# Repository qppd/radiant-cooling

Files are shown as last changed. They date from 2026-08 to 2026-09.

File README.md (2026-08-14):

# Radiant Cooling System

<p align="center">
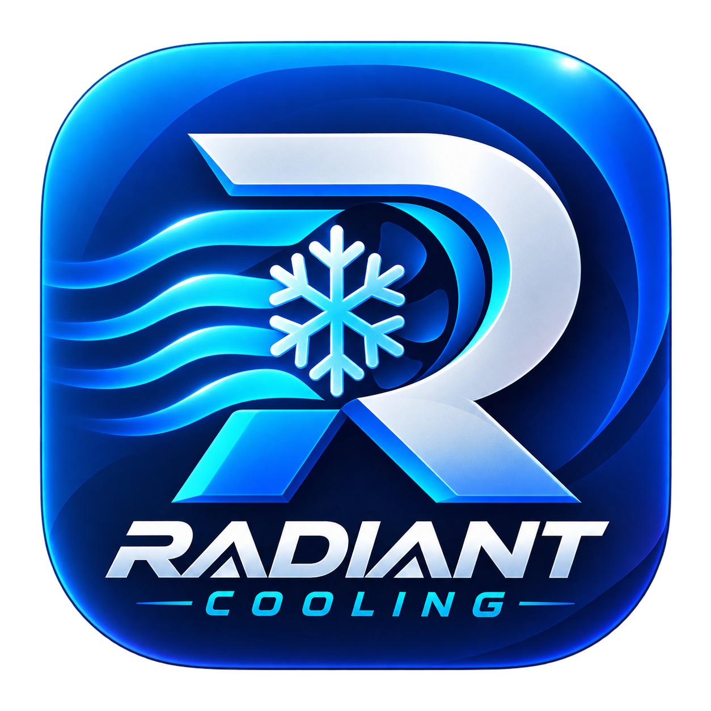
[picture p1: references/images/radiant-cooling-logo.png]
Radiant Cooling logo
  
</p>








> Intelligent radiant cooling for the home — three ESP32 boards that talk to
> each other over **ESP-NOW**, sync to **Firebase Realtime Database**, and are
> monitored from an **Android (Flutter)** app.

---

## Table of Contents

- [About](#about)
- [Features](#features)
- [System Architecture](#system-architecture)
- [Hardware](#hardware)
- [Repository Structure](#repository-structure)
- [Getting Started](#getting-started)
  - [Firmware](#firmware)
  - [Companion App](#companion-app)
- [Firebase Setup](#firebase-setup)
- [Documentation](#documentation)
- [Tech Stack](#tech-stack)
- [Roadmap](#roadmap)
- [License](#license)
- [Author](#author)

---

## About

A complete control and monitoring system for a **radiant cooling**
installation. Three ESP32 boards form a wireless mesh:

- **RadiantCoolingMonitor** (gateway) reads **6× DS18B20** water/pipe
  temperatures, collects data from the other boards, fetches outdoor
  weather (API key managed by the app), and pushes everything to Firebase —
  while also computing the chiller pump control (weather-driven +
  condensation protection).
- **WaterChillerController** switches **2 water pumps (SSR)** on command from
  the gateway.
- **DehumidifierController** holds indoor humidity at **55% RH** with its
  DHT22.

No MQTT broker, no cloud middleware — the boards use **ESP-NOW** directly,
and the gateway is the only device with Wi-Fi.

## Features

- **ESP-NOW mesh** — peer-to-peer, no router or broker required between boards
- **Two-way Firebase** — realtime *streaming* of config changes from the app,
  plus telemetry/state writes (Mobizt `FirebaseClient`, async, non-blocking)
- **Weather-aware pump control** — combines WeatherAPI.com dew point,
  indoor humidity, water/pipe temperatures and indoor air (DHT22);
  anti-condensation protection on the coldest pipe
- **Dehumidifier** — holds indoor RH at 55% with hysteresis
- **WiFiManager provisioning** — captive portal on first boot; hold the
  reset button 3 s to re-provision
- **Flutter Android app** — login/signup, live dashboard and settings
- **Modular firmware** — every component and library encapsulated in its own
  class (sensor, SSR, ESP-NOW, JSON, Firebase, Weather, Climate)

## System Architecture

```
┌────────────────┐   ESP-NOW   ┌──────────────────────────┐
│WaterChiller    │◄───────────►│RadiantCoolingMonitor     │
│Controller      │             │(gateway: WiFiManager +   │
└────────────────┘             │ Firebase stream +        │
┌────────────────┐   ESP-NOW   │ WeatherAPI + ESP-NOW)    │
│Dehumidifier    │◄───────────►│                          │
│Controller      │             └────────────┬─────────────┘
└────────────────┘                          │ HTTPS
                                            ▼
                             ┌────────────────────────────┐
                             │ Firebase Realtime Database  │
                             └────────────┬───────────────┘
                                          │ Firebase SDK
                                          ▼
                             ┌────────────────────────────┐
                             │ RadiantCooling App          │
                             │ (Flutter, Android)          │
                             └────────────────────────────┘
```

Full diagrams: [`docs/diagrams/`](docs/diagrams/) · [`docs/schematic/pin-map.md`](docs/schematic/pin-map.md)

## Hardware

| Board | Sensors | Actuators (SSR) | Role |
| --- | --- | --- | --- |
| `RadiantCoolingMonitor` | 6× DS18B20 (1-Wire, GPIO 18) | — | Gateway  |
| `WaterChillerController` | 1× DS18B20 (GPIO 22) | 2× SSR → pumps (19, 21) | Peer |
| `DehumidifierController` | 1× DHT22 (GPIO 32) | 1× SSR → dehumidifier (23)| Peer |

All pins are boot/Wi-Fi-safe for the 38-pin ESP32 variant — see the
[pin map](docs/schematic/pin-map.md).

Each board is powered by its **own** AC-DC supply (**220 V AC → 5 V DC,
3 A**, feeding the `5V`/`VIN` pin) — no shared rail between boards, see
[`references/power-supply.md`](references/power-supply.md).

## Repository Structure

```
radiant-cooling/
├── docs/
│   ├── api.md                 # ESP-NOW + Firebase protocol
│   ├── tech-stacks.md         # technology choices
│   ├── diagrams/              # architecture, block & flow diagrams
│   └── schematic/             # pin map & electrical references
├── references/                # reference material (datasheets, notes)
└── src/
    ├── app/
    │   └── RadiantCooling/    # Flutter companion app (Android)
    └── esp/
        ├── RadiantCoolingMonitor/     # gateway firmware
        ├── WaterChillerController/    # pump controller firmware
        ├── DehumidifierController/    # dehumidifier firmware
        └── README.md                  # firmware module documentation
```

## Getting Started

### Prerequisites

- [Arduino IDE 2.x](https://www.arduino.cc/en/software) with the
  **esp32 by Espressif** board package
- Arduino libraries: `DallasTemperature`, `OneWire`, `DHT sensor library`,
  `ArduinoJson`, `FirebaseClient` (Mobizt), `WiFiManager` (tzapu)
- [Flutter SDK](https://flutter.dev) (for the app)
- A [Firebase](https://firebase.google.com) project with Realtime Database
- A free [WeatherAPI.com](https://www.weatherapi.com) API key (managed from
  the Flutter app and delivered to the gateway at runtime — never compiled
  into the firmware)

### Firmware

1. Open each sketch folder in `src/esp/` with Arduino IDE, select the correct
   ESP32 board + COM port, and upload.
2. Fill in the config headers: on the gateway copy
   `FirebaseConfig.cpp.example` → `FirebaseConfig.cpp` (git-ignored), and
   set the peer/gateway MAC addresses, the `SYSTEM_ID`, and the
   `WEATHER_LOCATION` in `Config.h` for each board. The WeatherAPI key is
   managed from the Flutter app.
3. On first boot the gateway opens a **WiFiManager portal** (AP
   `RadiantCooling-AP`) — connect to it from your phone and enter your
   network credentials.
4. Fix the router to a fixed Wi-Fi channel (1, 6, or 11) so ESP-NOW works.

Details: [`src/esp/README.md`](src/esp/README.md)

### Companion App

```bash
cd src/app/RadiantCooling
flutter pub get
flutter run
```

Setup before first run:

1. Use the same Firebase project as the gateway; add the Android app
   (package `com.radiantcooling.radiant_cooling`), download
   `google-services.json` into `android/app/`, and wire the
   `google-services` Gradle plugin — see
   [`references/flutter-android-firebase.md`](references/flutter-android-firebase.md).
   Enable **Email/Password** in *Auth → Sign-in method* (the app's login
   and signup screens use it).
2. Copy `lib/config/app_config.example.dart` → `lib/config/app_config.dart`
   and fill in the **WeatherAPI.com key** (git-ignored). The app delivers
   the key to the gateway via `radiant/config/weather_key`; the **gateway
   fetches the weather itself**.
3. On first launch, **link** the app to your system by entering the
   `SYSTEM_ID` from the gateway's `Config.h` (the gateway publishes it in
   `radiant/devices/<SYSTEM_ID>`).

The app provides:

- **Login / Sign up** (email/password via Firebase Auth)
- **Device linking on first login** — new accounts (and any signed-in user
  with no linked system) are routed to a dedicated linking page where the
  `SYSTEM_ID` from the gateway is entered and validated against the device
  registry before the dashboard is shown
- **Dashboard** — live telemetry streamed from Firebase: gateway online
  status, outdoor weather (fetched by the ESP32), all pipe sensors
  (supply/return/ΔT/coldest pipe/tank + every DS18B20), pump + dehumidifier
  state, a live dew-point computation (Magnus formula from the streamed
  outdoor/indoor temp + humidity), and the gateway's condensation-safety
  values
- **Settings** — edit control parameters (comfort setpoint, dew-point
  margin, weather-cool threshold) and the dehumidifier target, link/change
  the system, manage the WeatherAPI key, and sign out

## Firebase Setup

1. Create a Firebase project and enable **Realtime Database**.
2. Enable **Email/Password** authentication in *Auth → Sign-in method*.
   Create a dedicated **gateway** account (e.g.
   `gateway@radiant-cooling.local`) and register a personal account for
   the app (the app has login and signup screens).
3. Copy `FirebaseConfig.cpp.example` → `FirebaseConfig.cpp` in the gateway
   folder and paste the database URL, **Web API key**, and (if using
   email/password auth) credentials — the file is git-ignored so secrets
   stay local.
4. Apply the security rules in
   [`docs/firebase-security-rules.json`](docs/firebase-security-rules.json)
   (paste into *Realtime Database → Rules* or deploy with
   `firebase deploy --only database`). The gateway must use a dedicated
   **email/password** account (replace the placeholder email in the rules) —
   see [`docs/api.md`](docs/api.md#8-firebase-security-rules--auth).

## Documentation

| Document | Contents |
| --- | --- |
| [`docs/api.md`](docs/api.md) | ESP-NOW protocol + Firebase data schema |
| [`docs/tech-stacks.md`](docs/tech-stacks.md) | Technology decisions |
| [`docs/diagrams/system-architecture.md`](docs/diagrams/system-architecture.md) | System layers |
| [`docs/diagrams/block-diagram.md`](docs/diagrams/block-diagram.md) | Hardware blocks |
| [`docs/diagrams/flow-chart.md`](docs/diagrams/flow-chart.md) | Control logic |
| [`docs/schematic/pin-map.md`](docs/schematic/pin-map.md) | Safe pin assignments |
| [`src/esp/README.md`](src/esp/README.md) | Firmware module layout |
| [`references/`](references/) | Per-topic references (ESP-NOW, Firebase, sensors, pins…) |

## Tech Stack

| Layer | Technology |
| --- | --- |
| Firmware | ESP32 (WROOM-32), C/C++, Arduino IDE |
| Mesh | ESP-NOW (built into the ESP32 core) |
| Cloud | Firebase Realtime Database + FirebaseClient |
| Weather | WeatherAPI.com (key in the Flutter app) |
| WiFi provisioning | WiFiManager (captive portal) |
| App | Flutter (Android) |

## Roadmap

- [x] ESP-NOW handlers + telemetry (receive queue, cmd/config processing, heartbeat) on all three boards
- [x] Wire the `onConfigStream` handler (control params + peer forwarding)
- [x] Flutter app: Firebase SDK, dashboard, control screens
- [x] First-login device linking page
- [x] Firebase security rules file in `docs/` (`firebase-security-rules.json`)
- [x] Unit tests for `ClimateControl` (dew point + pump decision, `src/esp/tests/`)
- [ ] `LICENSE` file

## License

This project is provided under the **MIT License** — a `LICENSE` file will be
added soon.

## Author

<p align="left">
  avatar
  <b>Sajed Lopez Mendoza</b><br/>
  <i>Building intelligent solutions</i><br/>
  136 Sitio Crossing, Ilaya Panaon, Unisan, Quezon 4305<br/>
  <a href="https://github.com/qppd">GitHub: @qppd</a> ·
  <a href="https://www.linkedin.com/in/sajed-mendoza">LinkedIn</a>
</p>

<br/>

Project by [**qppd**](https://github.com/qppd) · Built with ESP32, Flutter & Firebase

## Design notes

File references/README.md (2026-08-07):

# References

> Reference material behind the Radiant Cooling System — datasheets, library
> documentation, API notes, and guides that informed the code in `src/`.
> Each topic has its own markdown file.

| File | Topic |
| ---- | ----- |
| [`esp32-esp-now.md`](esp32-esp-now.md) | ESP-NOW peer-to-peer protocol (board mesh) |
| [`firebase-realtime-database.md`](firebase-realtime-database.md) | Firebase RTDB + Mobizt FirebaseClient library |
| [`wifimanager.md`](wifimanager.md) | WiFiManager captive-portal provisioning |
| [`ds18b20-temperature-sensor.md`](ds18b20-temperature-sensor.md) | DS18B20 + 1-Wire + DallasTemperature |
| [`dht22-humidity-sensor.md`](dht22-humidity-sensor.md) | DHT22 temperature/humidity sensor |
| [`solid-state-relay.md`](solid-state-relay.md) | SSR switching (pumps, dehumidifier) |
| [`weatherapi-com.md`](weatherapi-com.md) | WeatherAPI.com current-weather API |
| [`esp32-38pin-pinout.md`](esp32-38pin-pinout.md) | 38-pin ESP32 pinout, boot/strapping & Wi-Fi conflicts |
| [`power-supply.md`](power-supply.md) | 220V → 5V/3A supply (one per board) |
| [`dew-point-magnus.md`](dew-point-magnus.md) | Magnus-formula dew point calculation |
| [`arduino-ide-esp32.md`](arduino-ide-esp32.md) | Arduino IDE + ESP32 setup guide |
| [`flutter-android-firebase.md`](flutter-android-firebase.md) | Flutter Android + Firebase SDK |

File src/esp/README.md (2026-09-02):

# ESP32 Firmware

Three standalone Arduino sketches. **Every component type and every external
library is encapsulated in its own class module** — the `.ino` files are glue
only (wiring + control logic).

## Board folders

| Folder | Hardware | Role |
| --- | --- | --- |
| `RadiantCoolingMonitor/` | 6x DS18B20 (1-Wire): supply/return + 4 pipe temps | Gateway  |
| `WaterChillerController/`  | 3x DS18B20 adapter, compressor SSR, 2-channel pump relay | Peer |
| `DehumidifierController/`  | DHT22 (GPIO25), 1x SSR (GPIO23) -> dehumidifier | Peer |

## Module layout (same pattern in every sketch folder)

```
<BoardName>/
├── <BoardName>.ino     # glue: instantiate components, setup()/loop(), control logic
├── Config.h            # board config (MACs, SYSTEM_ID, constants); includes PINS_CONFIG.h + FirebaseConfig.h
├── PINS_CONFIG.h       # pin assignments - all GPIO wiring for the board
├── FirebaseConfig.h    # Firebase class declaration (endpoints + path layout) [gateway only]
├── FirebaseConfig.cpp  # REAL Firebase credentials (GIT-IGNORED; copy from FirebaseConfig.cpp.example) [gateway only]
├── TemperatureSensor.{h,cpp}   # component: DS18B20   (wraps OneWire + DallasTemperature)
├── HumiditySensor.{h,cpp}      # component: DHT22     (wraps DHT)
├── SsrOutput.{h,cpp}           # component: SSR output (wraps Arduino digital I/O)
├── WifiProvisioner.{h,cpp}     # wifi:     WiFiManager branded captive portal + auto-reconnect (wraps WiFiManager) [gateway only]
├── EspNowTransport.{h,cpp}     # comms:    ESP-NOW    (wraps WiFi + esp_now)
├── JsonProtocol.{h,cpp}        # protocol: JSON envelope (wraps ArduinoJson)
├── FirebaseSync.{h,cpp}        # cloud:    Firebase RTDB set/update + realtime stream (wraps FirebaseClient) [gateway only]
├── WeatherApi.{h,cpp}          # cloud:    WeatherAPI.com current weather (key from the app) [gateway only]
└── ClimateControl.{h,cpp}      # control:  dew point + pump decision [gateway only]
```

Pin assignments are kept in `PINS_CONFIG.h` (hardware wiring) and everything
else in `Config.h` (device identity, credentials, constants) — the two stay
separate so rewiring a board never touches the rest of the configuration.

All pins are drawn from the boot/Wi-Fi-safe pool for the 38-pin ESP32
variant — see [`docs/schematic/pin-map.md`](../../docs/schematic/pin-map.md)
for the avoidance table and wiring notes.

Each board only includes the modules it needs:

| Module | Monitor (gateway) | Chiller | Dehumidifier |
| --- | :---: | :---: | :---: |
| `TemperatureSensor`  | Yes (6x) | Yes (1x) | — |
| `HumiditySensor` | — | — | Yes |
| `SsrOutput` | — | Yes (×2) | Yes |
| `WifiProvisioner` | Yes | — | — |
| `EspNowTransport` | Yes | Yes | Yes |
| `JsonProtocol` | Yes | Yes | Yes |
| `FirebaseSync` | Yes | — | — |
| `WeatherApi` | Yes | — | — |
| `ClimateControl` | Yes | — | — |

## Why modules are duplicated across folders

Arduino IDE compiles each sketch folder standalone. Common modules
(`EspNowTransport`, `JsonProtocol`, `SsrOutput`, `TemperatureSensor`) are
therefore **copied into each sketch that needs them**. Keep them in sync, or
extract them into a shared custom library later (e.g. `libraries/RadiantCore/`)
if the duplication becomes a burden.

## Required libraries (Arduino IDE: Tools > Manage Libraries)

| Library | Used by | Notes |
| --- | --- | --- |
| `DallasTemperature` | monitor, chiller| depends on OneWire |
| `OneWire` | monitor, chiller| |
| `DHT sensor library`| dehumidifier | DHT22 |
| `ArduinoJson` | all | v7 (`JsonDocument`) |
| `FirebaseClient` | monitor | Mobizt; **v2.2.x+** (modern API: SSL client + SSE stream; the old `Firebase-ESP-Client` is deprecated) |
| `WiFiManager` | monitor | tzapu - captive-portal WiFi provisioning |

**ESP32 core 3.x** (by Espressif) is required — `EspNowTransport` and
`FirebaseSync` use the core-3.x / FirebaseClient-2.2.x APIs.

ESP-NOW (`esp_now.h`), WiFi, and `HTTPClient` (used by `WeatherApi`) are
built into the Arduino ESP32 core. The gateway fetches outdoor weather
from WeatherAPI.com itself; the API key is **managed by the Flutter app**
and delivered at runtime via `radiant/config/weather_key` — it is never
compiled into the firmware (see `docs/api.md §4`). Failed or stale fetches
(`WEATHER_STALE_S`, default 1 h) disable weather demand and fall back to
the indoor dew point.

WiFi credentials are **not** stored in code — they are entered once through
the WiFiManager captive portal (AP `RadiantCooling-AP`). Hold the gateway's
reset button (GPIO 33, see `PINS_CONFIG.h`) for ~3 s to erase them and
re-provision.

Firebase is **two-way** on the gateway (Mobizt `FirebaseClient`, async):
`setJson()`/`updateJson()` write telemetry/state to `radiant/telemetry/*`,
and `stream()` listens to `radiant/config` in real time. Enable
**Email/Password** auth in the Firebase console (create a dedicated gateway
account, e.g. `gateway@radiant-cooling.local`) and put the Web API key +
credentials in `FirebaseConfig.cpp` (`getApiKey()`, `getAuthEmail()`,
`getAuthPassword()`; copy from `FirebaseConfig.cpp.example` — it is
git-ignored). Note: `docs/firebase-security-rules.json` identifies the
gateway by `auth.token.email`, so the gateway must sign in with
email/password (not anonymous) when those rules are used.

## Implemented behavior

- **ESP-NOW receive** on every board is decoupled through a FreeRTOS queue:
  the callback only enqueues raw bytes; `loop()` drains, decodes
  (`JsonProtocol`), and applies/handles the message.
- **Gateway** reads supply/return + pipe temperatures (6x DS18B20), caches
  the latest peer readings for the chiller computation, forwards peer
  `telemetry`/`state` to Firebase, publishes its own telemetry + a retained
  heartbeat (`radiant/heartbeat/monitor`, includes the Wi-Fi channel), sends
  `set_pumps` on decision changes, and applies or forwards `radiant/config`
  stream changes. Cooling demand comes from the dehumidifier's DHT22 indoor
  temperature; the anti-condensation floor protects the coldest pipe/tank.
- **Chiller** executes `set_pumps` (`on`/`off`), reports a `state` message
  on pump changes, and streams `water_temp_c` telemetry every
  `TELEMETRY_S`.
- **Dehumidifier** applies `config` (setpoint/deadband) and `cmd`
  (`set_humidity_target`, `enable`/`disable`, `reset`), runs the 55 %%RH
  hysteresis loop, and streams `temp_c`/`humidity_pct` telemetry. After 3
  consecutive sensor read failures it fails safe (dehumidifier off).

## Unit tests

Host-machine tests for the pure-math modules live in
[`src/esp/tests/`](tests/README.md) (stub `Arduino.h`, no Arduino toolchain
needed). Currently covered: `ClimateControl` — Magnus dew point + the pump
decision logic (weather/sensor demands, condensation protection,
hysteresis, reference dew point selection).

```bash
cd src/esp/tests
./run_tests.sh     # requires g++ (Git Bash / WSL on Windows works)
```

## Working with the sketches

1. Add the ESP32 board manager URL and install "esp32 by Espressif".
2. Install the libraries above.
3. Open each board folder as a sketch in Arduino IDE, set the right board
   and COM port, and upload.
4. Fill in the config headers before flashing: `Config.h` (peer/gateway
   MACs, `SYSTEM_ID`), `FirebaseConfig.cpp` (Firebase URL + Web API key -
   copy from `FirebaseConfig.cpp.example`; it is git-ignored), and check
   `PINS_CONFIG.h` (pins). WiFi credentials are entered via the captive
   portal on first boot - nothing to fill in. The WeatherAPI key is
   entered in the Flutter app (delivered to the gateway at runtime); the
   weather location `WEATHER_LOCATION` is set in `Config.h`.

## References

- Architecture: [`docs/diagrams/system-architecture.md`](../../docs/diagrams/system-architecture.md)
- Hardware: [`docs/diagrams/block-diagram.md`](../../docs/diagrams/block-diagram.md)
- Control logic: [`docs/diagrams/flow-chart.md`](../../docs/diagrams/flow-chart.md)
- ESP-NOW + Firebase protocol: [`docs/api.md`](../../docs/api.md)
- Pin map (38-pin board, boot/Wi-Fi-safe): [`docs/schematic/pin-map.md`](../../docs/schematic/pin-map.md)
- References (ESP-NOW, Firebase, sensors, WiFiManager…): [`references/`](../../references/)

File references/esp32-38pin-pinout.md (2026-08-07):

# ESP32 38-Pin Variant — Pinout, Boot & Wi-Fi Conflicts

> Why the pins in every `PINS_CONFIG.h` were chosen for the 38-pin boards
> (WROOM-32 DevKit / NodeMCU-32S) with Wi-Fi + ESP-NOW running.

## Pins to AVOID

| Pins | Reason |
| --- | --- |
| `0`, `2`, `5`, `12`, `15` | **Strapping pins** — sampled at reset. GPIO 12 high at boot forces 1.8 V flash → boot failure. GPIO 2 often drives the onboard LED. |
| `6`–`11` | Wired to the **internal SPI flash** — never usable. |
| `1`, `3` | **UART0** — USB programming + Serial Monitor. |
| `0, 2, 4, 12, 13, 14, 15, 25, 26, 27` | **ADC2** — `analogRead()` fails while Wi-Fi is active (and Wi-Fi is always on here). |
| `34`–`39` | Input-only (no outputs, no internal pull-ups). |

## Digital-safe pool (used by this project)

`18, 19, 21, 22, 23, 32, 33`

| Board | Pin | Use |
| --- | --- | --- |
| `RadiantCoolingMonitor` | 18  | 1-Wire (6× DS18B20) |
| `RadiantCoolingMonitor` | 33  | WiFi reset button |
| `WaterChillerController`| 19, 21 | SSR pump 1, pump 2  |
| `WaterChillerController`| 22  | 1-Wire (1× DS18B20) |
| `DehumidifierController`| 23  | SSR dehumidifier |
| `DehumidifierController`| 32  | DHT22 |

## Key boot notes

- **GPIO 12** must be LOW at boot (pull-up there can brick flashing).
- **GPIO 0** LOW at boot = download/flash mode (handled by the USB-UART).
- ADC2 pins are safe for **digital** I/O, but were avoided entirely here to
  keep the option of analog reads and zero Wi-Fi surprises.

## Links

- ESP32 datasheet: <https://www.espressif.com/sites/default/files/documentation/esp32_datasheet_en.pdf>
- RNT — ESP32 pinout: <https://randomnerdtutorials.com/esp32-pinout-reference-gpios/>
- Stack Overflow — ADC2 + Wi-Fi conflict: <https://stackoverflow.com/questions/48100961/esp32-adc-accuracy-for-voltage-measurement>

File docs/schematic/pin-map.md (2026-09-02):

# ESP32 Pin Map (38-pin variant)

> Interactive 3D diagram: [`wiring-diagram.html`](wiring-diagram.html)
> (Three.js, top view — hover a component to see its wiring). The pins
> below are the authoritative values.

> Pin assignments for the three ESP32 boards. All boards run Wi-Fi/ESP-NOW,
> so every sensor/component pin is selected from the **digital-safe pool**
> that does not conflict with boot mode, the SPI flash, UART0, or ADC2.
>
> The authoritative pin values live in each sketch's `PINS_CONFIG.h`; this
> document is the reference for why those pins were chosen.

## Pins to AVOID on the 38-pin board

| Pins | Why |
| --- | --- |
| `0`, `2`, `5`, `12`, `15` | **Strapping pins** — sampled at reset to select boot mode. GPIO12 high at boot forces 1.8V flash → boot failure. GPIO2 often drives the onboard LED. |
| `6`–`11` | **SPI flash** — wired to the internal flash chip. Never use; breaks boot. |
| `1`, `3` | **UART0** — USB programming + Serial Monitor. |
| `0, 2, 4, 12, 13, 14, 15, 25, 26, 27` | **ADC2** — `analogRead()` fails while Wi-Fi is active (and we always run Wi-Fi/ESP-NOW). Avoid entirely. |
| `34`–`39` | **Input-only** — no output capability. Fine for inputs only. |

## Digital-safe pool (used by this project)

`18`, `19`, `21`, `22`, `23`, `32`, `33`

These are neither strapping, flash, UART0, nor ADC2 pins — safe for digital
I/O with Wi-Fi and ESP-NOW running.

## Per-board assignments

| Board | Pin | Component | Notes |
| --- | --- | --- | --- |
| `RadiantCoolingMonitor` | 18  | 1-Wire bus (6x DS18B20) | 4.7kΩ pull-up to 3V3 |
| `RadiantCoolingMonitor` | 33  | WiFi reset button | momentary switch to GND, INPUT_PULLUP; hold 3 s to erase WiFi credentials |
| `WaterChillerController`| 18  | SSR → compressor | SSR input (see wiring note)  |
| `WaterChillerController`| 19  | DS18B20 adapter → tank temperature | DAT; check adapter pull-up |
| `WaterChillerController`| 21  | 2-channel relay IN1 → water-in pump | Relay input (see wiring note) |
| `WaterChillerController`| 22  | 2-channel relay IN2 → water-out pump | Relay input (see wiring note) |
| `WaterChillerController`| 23  | DS18B20 adapter → ingoing water | DAT; check adapter pull-up |
| `WaterChillerController`| 32  | DS18B20 adapter → outgoing water | DAT; check adapter pull-up |
| `DehumidifierController`| 23  | SSR → dehumidifier | SSR input (see wiring note)  |
| `DehumidifierController`| 25  | DHT22 data | 10kΩ pull-up to 3V3 |
| (spare) | 19, 21, 22, 23, 32 | — | free on the gateway board |

## Wiring notes

- **DS18B20 adapter modules:** connect each module's `DAT` to its assigned
  GPIO, `GND` to ESP32 `GND`, and `VCC` to `3V3`. These sensors use separate
  1-Wire buses in this controller. Check the module: many adapters already
  include the required **4.7 kΩ pull-up** from `DAT` to `VCC`; add one only
  if it is absent. Do not connect adapter `VCC` to an ESP32 GPIO.
- **DHT22:** data pin needs a **10 kΩ pull-up** to 3V3.
- **Dehumidifier board power:** connect the regulated **5 V, 3 A** supply to
  ESP32 `VIN` and `GND`. Connect DHT22 `VCC` to `3V3`, DHT22 `GND` to ESP32
  `GND`, and the SSR input ground to the same common low-voltage `GND`.
- **SSR modules:** most SSR modules have an input that can be driven directly
  from a 3.3V GPIO (3-32V DC input). Confirm the module's input spec; if it
  needs more drive, buffer with a transistor/MOSFET.
- **WiFi reset button:** a momentary push button wired from GPIO 33 to GND
  (the internal pull-up is enabled in code). Hold for ~3 s to erase the
  saved WiFi credentials (WiFiManager) and restart — a captive portal then
  opens for new SSID/password. Holding it at power-up also erases the
  credentials (the portal opens without a restart).
- **ESP-NOW needs no pins** — it uses the radio. All boards run in STA mode.
- **Channel lock with WiFiManager:** the gateway connects to the router's
  channel automatically, so its ESP-NOW channel is whatever the router uses.
  The peers (STA mode, not associated) default to channel 1 and will not
  hear the gateway unless they match — **fix the router to channel 1, 6, or
  11** and/or configure the peers' channel to match the gateway.

## Power

Each board is fed by its **own** AC-DC power supply: **220 V AC → 5 V DC,
3 A**, connected to the board's `5V`/`VIN` pin (the onboard regulator steps
it down to 3.3 V). There is **no shared rail between boards** — each board
is galvanically isolated. Do **not** power sensors or SSR inputs from the 5V
pin. Total GPIO sink/source is shared — use the SSR to switch the
pump/dehumidifier mains loads (the SSR isolates them from the ESP32).

## References

- ESP32 38-pin pinout, boot & Wi-Fi conflicts: [`references/esp32-38pin-pinout.md`](../../references/esp32-38pin-pinout.md)
- Power supplies: [`references/power-supply.md`](../../references/power-supply.md)
- SSR wiring: [`references/solid-state-relay.md`](../../references/solid-state-relay.md)
- DS18B20 / DHT22 pull-up notes: [`references/ds18b20-temperature-sensor.md`](../../references/ds18b20-temperature-sensor.md), [`references/dht22-humidity-sensor.md`](../../references/dht22-humidity-sensor.md)

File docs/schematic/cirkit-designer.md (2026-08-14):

# Cirkit Designer Schematic

> Interactive wiring diagram for the radiant cooling system, drawn in
> **Cirkit Designer** (a free online circuit design tool). The schematic is
> versioned in the cloud; this page links to it and maps it to the firmware.

## Shareable link

<https://app.cirkitdesigner.com/project/5134caf3-4066-457c-ad06-4487625c0ef9>

Open in any browser — no login required to view. You can also duplicate the
project into your own workspace (Cirkit Designer → Project menu → Duplicate)
to edit or extend it.

## What it shows

The schematic models the three ESP32 boards and their wiring, matching the
layout in [`pin-map.md`](pin-map.md) and
[`docs/diagrams/block-diagram.md`](../diagrams/block-diagram.md):

| Board | Components in the schematic |
| --- | --- |
| `RadiantCoolingMonitor` | ESP32 (gateway) + 6× DS18B20 on one 1-Wire bus |
| `WaterChillerController` | ESP32 (peer) + 1× DS18B20 (tank) + 2× SSR → pumps |
| `DehumidifierController` | ESP32 (peer) + 1× DHT22 + 1× SSR → dehumidifier |

Each board sits on its own breadboard; the three are wired independently
(one 220 V → 5 V / 3 A supply per board, no shared rail) and only talk to
each other over the radio (ESP-NOW), so there are no inter-board wires in
the schematic.

## Sensor placement (physical installation)

- **6× DS18B20 (gateway, monitor)** — mounted on the chilled-water pipes
  **above the ceiling**: water **supply**, water **return**, and **4 pipe
  temperatures** along the run. All six share one 1-Wire bus (GPIO 18) with
  a 4.7 kΩ pull-up to 3V3.
- **1× DS18B20 (chiller)** — water temperature on the chiller tank (GPIO 22,
  4.7 kΩ pull-up). Feeds `water_temp_c` telemetry and the chiller fail-safe.
- **1× DHT22 (dehumidifier)** — indoor temperature + relative humidity
  (GPIO 32, 10 kΩ pull-up). The only humidity source → indoor dew point for
  the anti-condensation floor.

## Wiring notes

- **1-Wire (DS18B20):** one data line for all sensors on a board; 4.7 kΩ
  pull-up from the data line to 3V3. Use external 3V3 supply, not parasite
  power.
- **DHT22:** 10 kΩ pull-up on the data line.
- **SSR modules:** 3–32 V DC input — drive directly from a 3.3 V GPIO;
  buffer with a transistor/MOSFET if the module needs more drive. Always
  switch the mains load with the SSR; never wire pumps/dehumidifier through
  the board.
- **Power:** each board fed by its own **220 V AC → 5 V DC, 3 A** supply into
  `5V`/`VIN`. No shared rail between boards.
- **WiFi reset button (gateway):** GPIO 33 → GND, momentary; hold 3 s to
  erase WiFi credentials.

See [`pin-map.md`](pin-map.md) for the full pin-by-pin rationale (boot,
flash, UART0 and ADC2 avoidance on the 38-pin ESP32) and
[`references/README.md`](../../references/README.md) for the list of
electrical reference documents.

## Offline diagram

An interactive **3D wiring diagram** lives in this folder (no Cirkit
account needed):

- **`wiring-diagram.html`** — an interactive **Cirkit-style** flat 2D
  wiring diagram (Three.js, orthographic top view with dot grid, thin
  color-coded wires with junction dots). Pan/zoom to explore; hover/click
  a component to highlight its wires; toggles show/hide power, 1-Wire,
  GPIO and ESP-NOW groups. Open it in any browser (needs internet for the
  Three.js CDN).

Pin assignments in the schematic and `PINS_CONFIG.h` are kept in sync;
update both together when rewiring a board.

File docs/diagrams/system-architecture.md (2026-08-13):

# System Architecture

> High-level view of the Radiant Cooling System: the Flutter app, Firebase
> Realtime Database, the ESP32 mesh (ESP-NOW), and the physical HVAC plant.

## Overview

The system is organized into four logical layers:

| Layer | Components | Responsibility |
| --- | --- | --- |
| Application | `RadiantCooling` Flutter app (Android) | Monitoring, configuration, user interface |
| Cloud | Firebase Realtime Database + WeatherAPI.com | Shared data store; outdoor dew point for control |
| Controllers | ESP32 — `RadiantCoolingMonitor` (**gateway**), `WaterChillerController`, `DehumidifierController` | Local control loops, sensing, actuation |
| Plant | Water pumps (2, SSR), dehumidifier (SSR), DS18B20 + DHT22 sensors | Physical HVAC equipment |

**Key point:** the three ESP32 boards talk to each other over **ESP-NOW**
(no router or broker needed). Only `RadiantCoolingMonitor` connects to
Wi-Fi and Firebase, acting as the gateway between the mesh and the cloud.

## Diagram

```mermaid
flowchart TB
    subgraph APP["Application Layer"]
        UI["RadiantCooling App<br/>(Flutter - Android)"]
    end

    subgraph CLOUD["Cloud Layer"]
        FB[("Firebase Realtime Database")]
        WX[("WeatherAPI.com")]
    end

    subgraph CTRL["Controller Layer (ESP32 - ESP-NOW mesh)"]
        GW["RadiantCoolingMonitor<br/>(gateway - Wi-Fi + Firebase + ESP-NOW)"]
        WCC["WaterChillerController<br/>(ESP-NOW peer)"]
        DHC["DehumidifierController<br/>(ESP-NOW peer)"]
    end

    subgraph PLANT["Plant Layer (HVAC)"]
        T6["6x DS18B20<br/>(1-Wire)"]
        T1["1x DS18B20<br/>(water temp)"]
        DHT["DHT22<br/>(temp + humidity)"]
        P1["Water Pump 1"]
        P2["Water Pump 2"]
        DH["Dehumidifier"]
        LOOP["Radiant Cooling Loop"]
    end

    UI <-->|"Firebase SDK (HTTPS)"| FB
    FB <-->|"Firebase REST (HTTPS)"| GW
    GW <-->|"HTTPS"| WX

    GW <-->|"ESP-NOW"| WCC
    GW <-->|"ESP-NOW"| DHC

    GW ---|"1-Wire"| T6
    WCC ---|"1-Wire"| T1
    WCC ---|"SSR"| P1
    WCC ---|"SSR"| P2
    DHC ---|"DHT"| DHT
    DHC ---|"SSR"| DH

    P1 --- LOOP
    P2 --- LOOP
```

## Data flows

- **Sensors → app:** every board reads its own sensors (gateway: 6x
  DS18B20; chiller: 1x DS18B20; dehumidifier: 1x DHT22). Peers send their
  readings to the gateway over ESP-NOW; the gateway combines everything and
  writes to Firebase; the app reads via the Firebase SDK.
- **Weather → control:** the gateway polls WeatherAPI.com (API key managed
  by the app and delivered via `radiant/config/weather_key`) for the
  outdoor dew point/temperature and computes the chiller pump decision
  (weather + sensors + condensation protection, see
  `docs/diagrams/flow-chart.md`).
- **App → plant:** the app writes `config`/`cmd` in Firebase; the gateway
  detects the change and relays it to the right peer over ESP-NOW.

## Notes

- **Single Wi-Fi channel:** all boards must share the gateway's Wi-Fi
  channel for ESP-NOW to work alongside the router connection.
- The gateway buffers ESP-NOW packets in a FreeRTOS queue and writes to
  Firebase asynchronously — never inside the ESP-NOW callback.
- Interfaces between controllers and plant equipment are detailed in the
  block diagram and schematics.

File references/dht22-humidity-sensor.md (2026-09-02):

# DHT22 (AM2302) Humidity & Temperature Sensor

> Used on the dehumidifier board to measure indoor temperature + relative
> humidity — the gateway converts these to an indoor dew point.

## Key facts

- Measures relative humidity **0–100 %RH (±2 %)** and temperature −40..+80 °C
  (±0.5 °C).
- Single-wire digital protocol; one data pin + a **10 kΩ pull-up** to 3V3.
- Slow sampling: **max one read every ~2 s** — do not poll faster.
- Returns `NAN` when the read fails (timing/pin issues).
- Library: **DHT sensor library** (by Adafruit) in the Arduino Library Manager.

```cpp
#include <DHT.h>
DHT dht(PIN_DHT22, DHT22);

dht.begin();
float t = dht.readTemperature();   // °C
float h = dht.readHumidity();      // %RH
```

## How it is used here

- `HumiditySensor` module wraps the DHT library (dehumidifier board only).
- Wiring: DHT22 `DATA` to GPIO25, `VCC` to ESP32 `3V3`, and `GND` to ESP32
  `GND`. Keep the DHT22, ESP32, and SSR input on the same common ground.
- The 55 %RH setpoint control reads this sensor directly; the reading is also
  sent to the gateway over ESP-NOW for the dew-point computation.

## Links

- Datasheet: <https://www.sparkfun.com/datasheets/Sensors/Temperature/DHT22.pdf>
- DHT sensor library: <https://github.com/adafruit/DHT-sensor-library>
- RNT — DHT11/DHT22 with ESP32: <https://randomnerdtutorials.com/esp32-dht11-dht22-temperature-humidity-sensor-arduino-ide/>

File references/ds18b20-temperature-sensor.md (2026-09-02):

# DS18B20 Temperature Sensor (1-Wire)

For the 3-wire adapter modules, connect `DAT`, `GND`, and `VCC` as follows:

- `DAT` goes to the assigned ESP32 GPIO.
- `GND` goes to ESP32 `GND`.
- `VCC` goes to regulated `3V3`.
- Check whether the adapter includes the required 4.7 kΩ pull-up resistor.

> Digital temperature sensor used on the gateway (6×) and the chiller board
> (1×). All sensors share a single GPIO via the 1-Wire bus.

## Key facts

- ±0.5 °C accuracy (−10..+85 °C); 9–12 bit resolution; measures from −55 to
  +125 °C.
- **1-Wire bus:** every DS18B20 has a unique 64-bit ROM address, so **many
  sensors share one data pin** (addressed by index after enumeration).
- Requires a **4.7 kΩ pull-up** resistor from the data line to 3V3.
- ~750 ms conversion time at 12-bit resolution.
- Returns `-127.0` (`DEVICE_DISCONNECTED_C`) when a sensor is missing.

### Libraries (Arduino Library Manager)

- **OneWire** (bus protocol) + **DallasTemperature** (high-level API).

```cpp
#include <OneWire.h>
#include <DallasTemperature.h>

OneWire oneWire(PIN);
DallasTemperature sensors(&oneWire);

sensors.begin();                        // enumerate devices
sensors.requestTemperatures();          // start conversion (async)
float t = sensors.getTempCByIndex(0);   // read sensor 0 after ~750 ms
```

## How it is used here

- `TemperatureSensor` module wraps each bus. The gateway uses one bus for six
  sensors; the chiller uses three separate buses: outgoing water on GPIO 32,
  ingoing water on GPIO 23, and the water-chiller tank on GPIO 19.
- Room temperatures feed the pump-control computation (`ClimateControl`).

## Links

- Datasheet (Analog Devices): <https://www.analog.com/en/products/ds18b20.html>
- RNT — multiple DS18B20 with ESP32: <https://randomnerdtutorials.com/esp32-multiple-ds18b20-temperature-sensors/>
- DallasTemperature library: <https://github.com/milesburton/Arduino-Temperature-Control-Library>

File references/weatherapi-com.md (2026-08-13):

# WeatherAPI.com

> Free-tier weather API called by the **gateway (monitor board)** for the
> outdoor temperature and **dew point** that drive the chiller pump control;
> the API key is managed from the Flutter app.

## Key facts

- **Current weather endpoint:**
  `GET https://api.weatherapi.com/v1/current.json?key=<API_KEY>&q=<LOCATION>`
- The `current` object includes `temp_c`, `humidity`, and — critically —
  **`dewpoint_c`** (outdoor dew point in °C).
- Free tier has a **daily/monthly call budget** — keep the poll interval
  conservative (the gateway polls every 15 min by default).
- `q` can be a city name, lat/lon, or postal code.

## How it is used here

- The **gateway (monitor board)** calls `current.json` itself; the API key
  is **managed by the Flutter app** (`lib/config/app_config.dart`,
  git-ignored; copy from `app_config.example.dart`) and delivered at
  runtime via `radiant/config/weather_key` (Firebase) — it is never
  compiled into the firmware.
- The gateway polls every `WEATHER_POLL_S` (default 15 min), parses
  `current.temp_c`, `current.humidity` and `current.dewpoint_c`, and feeds
  them into `ClimateControl`.
- Failed/stale fetches (no valid data within `WEATHER_STALE_S`, default
  1 h) disable weather demand and fall back to the indoor DHT22 dew point
  alone.
- The outdoor dew point is combined with the indoor dew point (DHT22) —
  reference = the **higher** of the two — to set the anti-condensation water
  floor in `ClimateControl`.

## Links

- Docs: <https://www.weatherapi.com/docs/>
- Pricing / free tier: <https://www.weatherapi.com/pricing.aspx>

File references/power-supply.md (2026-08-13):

# Power Supply — 220V AC → 5V DC (3A, one per board)

> Every ESP32 board is powered by its **own** AC-DC power supply:
> **220 V AC → 5 V DC, 3 A**. No shared rail between boards — each board is
> fully isolated from the others.

## Specification

| Parameter | Value |
| --- | ----- |
| Input | 220 V AC (mains) |
| Output | 5 V DC, 3 A (15 W) |
| Quantity  | 3× — one per board |
| Feed | 5 V → board **5V/VIN** pin → onboard 3.3 V regulator → ESP32 + sensors |

## Wiring notes

- **L (live) / N (neutral)** go to the PSU input; **PE (earth)** to the
  enclosure/chassis if the PSU provides it.
- Add a **fuse (e.g. 2 A)** on the live input for protection.
- PSU **5 V +** → board `5V`/`VIN`; PSU **GND −** → board `GND`.
- The SSR-switched loads (water pumps, dehumidifier) are on **separate mains
  circuits** — the 5 V supplies only power the logic boards and sensors.
- One shared 5 V rail across boards is **not** used (keeps grounds isolated
  per board).

## Safety

- **Warning:** 220 V mains work requires proper care: fuse the input, use an
  insulated enclosure, and keep all mains wiring away from the low-voltage
  side.
- Never connect sensors or SSR inputs to the 5 V pin; GPIOs are 3.3 V.
- The SSR isolates the load side — always switch the **load** with the SSR,
  never wire the pumps/dehumidifier through the board.

## How it is used here

- One supply feeds `RadiantCoolingMonitor`, one feeds `WaterChillerController`,
  one feeds `DehumidifierController` (see `docs/diagrams/block-diagram.md`).
- Power-on sequences are independent — a fault on one board never affects the
  others.

## Links

- AC-DC power supply basics: <https://en.wikipedia.org/wiki/AC%E2%80%93DC_adapters>
- ESP32 power requirements: <https://docs.espressif.com/projects/esp32/en/latest/_images/esp32_pinout.png>

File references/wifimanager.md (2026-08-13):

# WiFiManager (tzapu)

> Captive-portal WiFi provisioning library — lets the gateway board connect
> to any network **without hardcoded SSID/password**.

## Key facts

- Library: **WiFiManager** by tzapu (maintained by tablatronix); install via
  Arduino Library Manager.
- On boot it tries the **saved credentials**; if none exist (or the network
  is unreachable) it starts a **captive portal** AP the user joins from a
  phone, enters SSID/password, and the values are saved to flash.
- Credentials can be erased at runtime with `resetSettings()`.

### API used in this project (`WifiProvisioner` module)

```cpp
#include <WiFiManager.h>
WiFiManager wm;

bool connected = wm.autoConnect("AP-Name");   // returns true when joined
wm.resetSettings();                           // erase saved SSID/password
wm.setConfigPortalTimeout(180);               // portal timeout (s)
wm.setConnectTimeout(15);                     // connection timeout (s)
```

## How it is used here

- `WifiProvisioner` (gateway only) wraps WiFiManager.
- On first boot the portal AP **`RadiantCooling-AP`** opens.
- **Reset button (GPIO 33):** hold ~3 s → `resetSettings()` + `ESP.restart()`;
  holding it at power-up also erases credentials so the portal re-opens.
- **Warning:** The gateway's Wi-Fi channel becomes the router's channel — ESP-NOW peers
  must match it (fix the router to 1/6/11, see `docs/schematic/pin-map.md`).

## Links

- GitHub: <https://github.com/tzapu/WiFiManager>
- RNT — ESP32 WiFiManager: <https://randomnerdtutorials.com/esp32-wifimanager-asyncweb-mongoose/configuration-manage-network/>
- RNT — reset WiFiManager settings with a button: <https://randomnerdtutorials.com/esp32-wifimanager-asyncweb-mongoose/reset-settings-button/>

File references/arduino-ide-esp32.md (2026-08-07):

# Arduino IDE + ESP32 Setup

> Toolchain used for all three firmware sketches.

## Steps

1. Install [Arduino IDE 2.x](https://www.arduino.cc/en/software).
2. **Add the ESP32 board manager URL** in *File → Preferences*:
   `https://raw.githubusercontent.com/espressif/arduino-esp32/gh-pages/package_esp32_index.json`
3. *Tools → Board → Boards Manager* → search **esp32** → install
   **"esp32 by Espressif"**.
4. Install libraries via *Tools → Manage Libraries*:

| Library | Boards |
| --- | --- |
| `OneWire` | monitor, chiller |
| `DallasTemperature` | monitor, chiller |
| `DHT sensor library` | dehumidifier |
| `ArduinoJson` | all |
| `FirebaseClient` | monitor (Mobizt) |
| `WiFiManager` | monitor (tzapu) |

5. Open each board folder in `src/esp/` as a sketch, select the right ESP32
   board + COM port, and upload.

## Notes

- ESP-NOW (`esp_now.h`), `WiFi`, and `HTTPClient` are built into the core —
  no extra installs.
- `.h` / `.cpp` files inside a sketch folder are compiled automatically.

## Links

- Arduino-ESP32 core: <https://github.com/espressif/arduino-esp32>
- Board manager JSON: <https://raw.githubusercontent.com/espressif/arduino-esp32/gh-pages/package_esp32_index.json>
- Installing ESP32 boards: <https://docs.espressif.com/projects/arduino-esp32/en/latest/installing.html>

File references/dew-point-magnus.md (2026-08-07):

# Dew Point — Magnus Formula

> The indoor dew point is computed from the dehumidifier's DHT22
> (temperature + relative humidity) using the Magnus formula.

## Formula

```
α  = (a · T) / (b + T) + ln(RH / 100)
Td = (b · α) / (a − α)
```

with:

- `T` — air temperature (°C)
- `RH` — relative humidity (%)
- `a = 17.62`, `b = 243.12 °C` (constants for 0..60 °C range)

Guarded against `RH ≤ 0` (log(0) → NaN) — invalid readings yield no indoor
dew point and the outdoor (weather) value is used alone.

## Why it matters here

Condensation forms when a surface is colder than the dew point of the air
touching it. Radiant cooling keeps the chilled-water supply above
`dew point + margin`:

```
refDewPoint = max(outdoorDewPoint (WeatherAPI), indoorDewPoint (DHT22))
waterFloor  = refDewPoint + dewpoint_margin_c
```

Implemented in the `ClimateControl` module (`dewPointC()` and `decidePumps()`).

## Links

- Magnus formula (Dew point article): <https://en.wikipedia.org/wiki/Dew_point>
- Arden Buck equation (similar approximation): <https://en.wikipedia.org/wiki/Arden_Buck_equation>

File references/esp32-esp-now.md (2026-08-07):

# ESP-NOW

> Espressif's connectionless peer-to-peer protocol — the wireless link
> between the three ESP32 boards in this project (no router or broker).

## Key facts

- Built into the ESP32 silicon and the Arduino ESP32 core — **no external
  library** (`#include <esp_now.h>`).
- **Max payload: 250 bytes** (ESP-NOW v1.0); newer ESP32 variants with
  ESP-NOW v2.0 support up to 1470 bytes.
- Works in **STA mode without associating** to a router, but the interface
  still occupies a Wi-Fi channel.
- **Channel lock:** all peers must operate on the same channel as the
  gateway's router connection. Peers that are not associated default to
  channel 1 → classic silent-failure mode.
- Best-effort delivery — no built-in acknowledgement (the send callback
  reports delivery status per peer).

## API used in this project (`EspNowTransport` module)

```cpp
WiFi.mode(WIFI_STA);                 // required
esp_now_init();                      // returns ESP_OK on success
esp_now_peer_info_t peer = {};
memcpy(peer.peer_addr, mac, 6);      // peer MAC
esp_now_add_peer(&peer);             // register a peer
esp_now_register_recv_cb(cb);        // void cb(const uint8_t*, const uint8_t*, int)
esp_now_register_send_cb(cb);        // void cb(const uint8_t*, esp_now_send_status_t)
esp_now_send(mac, data, len);        // queue a message to a peer
```

## How it is used here

- `RadiantCoolingMonitor` (gateway) registers both controller boards as peers.
- `WaterChillerController` and `DehumidifierController` register the gateway
  and send telemetry; they receive `set_pumps` / config commands.
- Message payloads are JSON (≤ 250 B) encoded by the `JsonProtocol` module —
  see `docs/api.md`.

## Links

- ESP-IDF ESP-NOW API reference: <https://docs.espressif.com/projects/esp-idf/en/stable/esp32/api-reference/network/esp_now.html>
- Arduino-ESP32 ESP_NOW examples: <https://github.com/espressif/arduino-esp32/tree/master/libraries/ESP_NOW>
- Random Nerd Tutorials — ESP32 ESP-NOW: <https://randomnerdtutorials.com/esp-now-esp32-arduino-ide/>

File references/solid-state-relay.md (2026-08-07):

# Solid State Relay (SSR)

> Used to switch the two water pumps (chiller board, 2×) and the dehumidifier
> (dehumidifier board, 1×). SSRs are driven by the ESP32 GPIOs and isolate
> the low-voltage logic from the mains/load side.

## Key facts

- **DC-input AC-output SSRs** are the common hobby type: input accepts
  **3–32 V DC**, output switches the mains load.
- **Zero-crossing** models switch near the AC zero point → less EMI, but the
  response adds up to half a mains cycle; good for pumps/heaters.
- The ESP32's **3.3 V GPIO can usually drive the input directly**, but always
  check the module's input spec — if it needs more current, buffer with a
  transistor/MOSFET.
- Always switch the **load side** (pump / dehumidifier) with the SSR — never
  power them from the board's pins.

## How it is used here

- `SsrOutput` module wraps a single SSR as a digital output (`on()` / `off()`,
  starts OFF in `begin()`).
- Pins: chiller pumps → GPIO 19, 21; dehumidifier → GPIO 23 (boot/Wi-Fi-safe,
  see `docs/schematic/pin-map.md`).

## Links

- Guide — SSR basics: <https://www.electronics-tutorials.ws/blog/solid-state-relay.html>
- RNT — ESP32 control a relay (concept applies to SSRs): <https://randomnerdtutorials.com/esp32-relay-module-ac-control/>

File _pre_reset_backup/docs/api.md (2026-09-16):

# API

> Communication interfaces for the Radiant Cooling System.
>
> Two data planes:
> 1. **ESP-NOW** — wireless link between the ESP32 boards (no Wi-Fi network
>    required between them).
> 2. **Firebase Realtime Database** — the cloud store shared by the gateway
>    board and the Flutter app.
>
> **Status: implemented** — matches the firmware in `src/esp/` and the
> Flutter app in `src/app/`; details evolve with the code.

## 1. Overview

```
┌────────────────┐   ESP-NOW    ┌───────────────────────┐
│WaterChiller    │◄────────────►│RadiantCoolingMonitor  │
│Controller      │              │(gateway: Wi-Fi +      │
└────────────────┘              │ Firebase + ESP-NOW)   │
┌────────────────┐   ESP-NOW    │                       │
│Dehumidifier    │◄────────────►│                       │
│Controller      │              └───────────┬───────────┘
└────────────────┘                          │ HTTPS (REST)
                                            ▼
                                ┌───────────────────────┐
                                │Firebase Realtime      │
                                │Database               │
                                └───────────┬───────────┘
                                            │ Firebase SDK
                                            ▼
                                ┌───────────────────────┐
                                │RadiantCooling App     │
                                │(Flutter, Android)     │
                                └───────────────────────┘
```

- **Sensors → cloud:** monitor reads sensors, receives ESP-NOW packets from
  the two controllers, and writes everything to Firebase.
- **Cloud → plant:** the app writes commands/config to Firebase; the gateway
  streams those paths (real time) and forwards changes to the right board
  via ESP-NOW.

## 2. Device IDs

| Device ID  | Board / role |
| --- | --- |
| `monitor`  | `RadiantCoolingMonitor` — **gateway** |
| `chiller`  | `WaterChillerController` — ESP-NOW peer  |
| `dh` | `DehumidifierController` — ESP-NOW peer  |

Each installation also has a user-facing **system ID** (`SYSTEM_ID`, e.g.
`RADIANT-001`) in the gateway's `Config.h`. The gateway publishes it in the
**device registry** (`radiant/devices/<SYSTEM_ID>`) and in its heartbeat —
the Flutter app uses it to **link** to this specific system (see §6).

## 3. Firebase Realtime Database structure

Database URL shape: `https://<project>.firebaseio.com/`

```
radiant/
├── telemetry/
│   ├── monitor/                 # gateway's own sensors
│   │   └── latest               # { temps_c: [6 values] }
│   ├── chiller/
│   │   └── latest
│   └── dh/
│       └── latest
├── state/                       # current actuator states
│   ├── chiller/                 # { pump1, pump2 }
│   └── dh/                      # { dehumidifier }
├── config/                      # writable by app, consumed by firmware
│   ├── control/                 # gateway control params (chiller computation)
│   │   └── params               # { comfort_setpoint_c, dewpoint_margin_c, weather_cool_temp_c }
│   ├── weather_key/             # WeatherAPI key, app → gateway (see §4)
│   └── dh/                      # { humidity_setpoint_pct: 55, humidity_deadband_pct }
├── heartbeat/                   # gateway writes, app can watch
│   └── monitor/                 # { online, device_id, firmware, ts }
└── devices/                     # device registry (system linking)
    └── <SYSTEM_ID>/             # { online, device_id, firmware, ts }
```

### 3.1 `telemetry/<device>/latest`

`monitor` (6x DS18B20 on the chilled-water pipes + computed control values;
`temps_c` = [supply, return, pipe1..pipe4]):

```json
{ "temps_c": [16.2, 16.8, 17.1, 22.4, 23.1, 22.8],
  "supply_c": 16.2, "return_c": 16.8, "coldest_pipe_c": 16.2,
  "delta_t_c": 0.6, "outdoor_temp_c": 31.2, "outdoor_dewpoint_c": 24.5,
  "outdoor_humidity_pct": 66.0, "dew_point_c": 18.0,
  "water_floor_c": 20.0, "pumps": "on", "ts": 1786119829 }
```

`chiller` (three DS18B20 adapters + compressor and pump states):

```json
{ "outgoing_temp_c": 16.2, "ingoing_temp_c": 16.8, "tank_temp_c": 17.1,
  "water_temp_c": 17.1, "compressor": "on", "pump1": "on", "pump2": "off",
  "ts": 1786119829 }
```

`dh` (DHT22):

```json
{ "temp_c": 24.3, "humidity_pct": 52.0, "ts": 1786119829 }
```

> `ts` is stamped by the **gateway** (NTP time once synced, uptime-seconds
> as a fallback) when it forwards peer telemetry to Firebase — peers send
> the raw payload without a timestamp.

### 3.2 `state/<device>`

```json
{ "pump1": "on", "pump2": "off" }       // chiller
{ "dehumidifier": "on" }                 // dh
```

### 3.3 `config/<device>` (app → firmware)

```json
{ "comfort_setpoint_c": 24.0, "dewpoint_margin_c": 2.0, "weather_cool_temp_c": 28.0 }  // control (gateway)
{ "humidity_setpoint_pct": 55.0, "humidity_deadband_pct": 5.0 }                        // dh
```

| Config key | Node | Type | Meaning |
| --- | --- | --- | --- |
| `comfort_setpoint_c` | `control` | float  | Indoor air (DHT22) above this → cooling demand (°C) |
| `dewpoint_margin_c` | `control` | float  | Water floor = dew point + margin (°C) |
| `weather_cool_temp_c` | `control` | float  | Outdoor temp above this → weather demand (°C) || `humidity_setpoint_pct` | `dh` | float  | Dehumidifier target RH (%) — **55** |
| `humidity_deadband_pct` | `dh` | float  | RH hysteresis (%) |
| `weather_key` (node) | `weather_key` | string | WeatherAPI key delivered to the gateway — see §4 |

## 4. Weather API (monitor board fetches; key managed by the app)

The **monitor (gateway) board** fetches the current outdoor conditions
itself from WeatherAPI.com. The API key is **managed by the Flutter app**
and delivered to the gateway at runtime — it is never compiled into the
firmware.

- **Endpoint (gateway):** `GET https://api.weatherapi.com/v1/current.json?key=<KEY>&q=<LOCATION>&aqi=no`
- **Fields used:** `current.temp_c`, `current.humidity`, `current.dewpoint_c`
- **Key delivery:** the app writes the key to `radiant/config/weather_key`
  (a string); the gateway streams it and keeps it in RAM. A gateway reboot
  loses it, so the app re-sends it on launch / (re)link.
- **Throttle:** the gateway polls every `WEATHER_POLL_S` (default 900 s =
  15 min) to stay inside the free-tier daily call budget.
- **Failure handling:** on a failed fetch (bad/absent key, API unreachable)
  the last good values are kept; once older than `WEATHER_STALE_S` (default
  3600 s = 1 h) weather demand turns off and the condensation floor falls
  back to the **indoor** dew point only.
- The app stores the key in `lib/config/app_config.dart` (git-ignored —
  copy from `app_config.example.dart`) or enters it in the app.

## 5. ESP-NOW protocol

- **Built into the Arduino ESP32 core** (`esp_now.h`) — no external library.
- **Max payload:** 250 bytes (v1.0). Keep messages compact.
- **Channel lock:** all boards must operate on the same Wi-Fi channel as the
  gateway's router connection (ESP-NOW and station mode share the channel).
- Peer MAC addresses are registered on each board (see firmware sketches).

### 5.1 Message envelope (JSON, ≤ 250 B)

```json
{ "v": 1, "t": "telemetry", "src": "chiller", "seq": 42,
  "d": { "water_temp_c": 16.2, "pump1": "on", "pump2": "off" } }
```

| Field | Values | Meaning |
| ----- | --- | --- |
| `v` | int | Protocol version (starts at 1) |
| `t` | `telemetry`, `state`, `cmd`, `config`, `status` | Message type |
| `src` | `monitor`, `chiller`, `dh` | Sender device ID |
| `seq` | unsigned int | Sequence number (dedupe) |
| `d` | object | Type-specific payload |

> **Size note:** JSON keeps the protocol readable, but the full telemetry
> payload plus ArduinoJson overhead approaches the 250 B limit. If payloads
> grow, fall back to a packed binary struct (`__attribute__((packed))`).

### 5.2 Message types

| Type | Direction | Payload example |
| --- | --- | --- |
| `telemetry` | peer → gateway | `{ "water_temp_c": 16.2, "pump1": "on", ... }` |
| `state` | peer → gateway | `{ "pump1": "on", "pump2": "off" }` |
| `cmd` | gateway → peer | `{ "cmd": "set_pumps", "value": "on" }` |
| `config` | gateway → peer | `{ "comfort_setpoint_c": 24.0, "dewpoint_margin_c": 2.0 }` |
| `status` | both | `{ "online": true, "firmware": "0.1.0" }` |

### 5.3 Supported commands (`cmd`)

| Command | Target  | Value |
| --- | --- | --- |
| `set_pumps` | chiller | `"on"` / `"off"` |
| `set_humidity_target`  | dh | number (%RH) |
| `enable` / `disable` | any | - |
| `reset` | any | - |

## 6. Data flows

### Telemetry (sensors → app)
1. Peers read sensors, send `telemetry`/`state` to gateway over ESP-NOW.
2. Gateway (receive callback) pushes packets into a FreeRTOS queue.
3. Gateway `loop()` drains the queue, computes control values, and writes
   `telemetry/<device>/latest` to Firebase using the **Firebase-ESP-Client**
   library (async, non-blocking).

### Chiller control (computed on the gateway)
1. The gateway polls WeatherAPI.com (key delivered by the app via
   `radiant/config/weather_key`) and combines the outdoor dew point, the
   indoor DHT22 temperature + humidity, the chilled-water supply/return +
   pipe temperatures (6x DS18B20) and the chiller tank temperature.
2. Reference dew point = **higher of outdoor/indoor**; water floor = dew
   point + `dewpoint_margin_c` (anti-condensation).
3. Pumps run when **weather demand** AND **sensor demand** (indoor DHT22
   temperature above setpoint) AND the **coldest** pipe/tank temperature
   is safely above the floor (see `docs/diagrams/flow-chart.md`).
4. On a decision change, the gateway sends the `set_pumps` command to the
   chiller over ESP-NOW.### Commands (app → plant)
0. **Linking:** on first login (new account, or any signed-in user with no
   linked system) the app shows a dedicated linking page asking for the
   system ID; it validates it against the device registry
   (`radiant/devices/<SYSTEM_ID>`, written by the gateway) and stores it
   locally before the dashboard is shown. From then on the app reads only
   that system's telemetry/state/heartbeat.
1. App writes `config/<node>` in Firebase.
2. The gateway **streams** `radiant/config` in real time (Firebase-ESP-Client
   `stream()` ) — changes arrive immediately, no polling.
3. On change, the gateway applies `config/control` locally or forwards a
   `cmd`/`config` ESP-NOW message to the right peer.
4. Peer applies the change and reports new `state` back.

## 7. Reliability & error handling

- **QoS:** ESP-NOW is best-effort with no ACK/retry in the firmware.
  Peers publish fresh `telemetry`/`state` on a fixed cycle, and the gateway
  forwards the latest snapshot to Firebase — a lost packet is simply
  overwritten by the next cycle. The `seq` field exists for future gap
  detection/deduplication.
- **Retained state:** Firebase stores the latest state, so the app always
  shows the last known values.
- **Heartbeat:** the gateway writes `heartbeat/monitor` with `online` and
  `ts`; the app can show connectivity from this path.
- **Peer presence:** peers never touch Firebase directly — their online
  status can be inferred from the freshness of `telemetry/<peer>/latest`.
  The app currently surfaces the gateway heartbeat; peer data appears on
  the dashboard as soon as a peer reports.
- **Unknown commands** are ignored and logged on the peer.

## 8. Firebase security rules & auth

Realtime Database **security rules** decide who can read/write each path.
Sensible defaults for this system:

| Path | Read | Write |
| --- | --- | --- |
| `radiant/telemetry/**`  | app | gateway |
| `radiant/state/**` | app | gateway |
| `radiant/config/**` | app + gateway | app |
| `radiant/heartbeat/**`  | app | gateway |
| `radiant/devices/**` | app | gateway |

**Ready-to-use rules:** [`firebase-security-rules.json`](firebase-security-rules.json) —
paste the file contents into Firebase console → Realtime Database → Rules
(or deploy via `firebase deploy --only database`).

- The **gateway** authenticates via Firebase-ESP-Client — **email/password with a
  dedicated account** (e.g. `gateway@radiant-cooling.local`). The rules above
  identify the gateway by `auth.token.email` (replace the placeholder email
  with the account you create), so **anonymous sign-in cannot be used for the
  gateway** with these rules — the writer role would be indistinguishable
  from the app.
- The **app** authenticates via the Firebase SDK with **email/password**
  (login and signup screens in the app); any authenticated user may read
  telemetry/state/config/heartbeat and write `config/**`.
- `config/**` is written by the app and read by both the app (dashboard
  display) and the gateway (stream).
- `config/weather_key` is special-cased: written by the app, readable only
  by the gateway (it holds the WeatherAPI key).
- Rules are versioned alongside the data paths.

## 9. Versioning

- Firebase paths are versioned under `radiant/v1/` once stabilized.
- ESP-NOW payload fields are additive-only after v1; breaking changes bump
  the `v` field in the message envelope (see §5.1).

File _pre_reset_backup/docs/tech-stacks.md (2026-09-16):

# Technology Stacks

<p align="center">
  Radiant Cooling logo
</p>

> Languages, frameworks, and tools used across the Radiant Cooling System.

## Firmware (ESP32 controllers)

| Layer | Choice | Notes |
| --- | --- | --- |
| MCU | ESP32 | Wi-Fi + BLE in one module, ample GPIO |
| Language | C / C++ | Standard for embedded controllers |
| Build | Arduino IDE | One sketch per controller; ESP32 core via Board Manager |
| Framework  | Arduino (`esp32` core) | Decided: Arduino IDE + Arduino framework |
| Mesh | **ESP-NOW** (built into the ESP32 core) | Board-to-board comms, no router/broker required |
| WiFi | **WiFiManager** (tzapu) — gateway only | Branded captive portal (static AP IP), auto-reconnect; no hardcoded SSID/password |
| Cloud | **Firebase-ESP-Client** v4.4.17 (Mobizt) — gateway only | Async Firebase Realtime Database REST client (setJSON, beginStream, readStream) |
| Encoding | ArduinoJson | Compact JSON payloads (≤ 250 B) over ESP-NOW |
| Sensors | OneWire / DallasTemperature, DHT | Install via Arduino Library Manager |
| Code layout | One class module per component + per library | See [`src/esp/README.md`](../src/esp/README.md)  |

## Companion application (Flutter, Android)

| Layer | Choice | Notes |
| --- | --- | --- |
| UI | Flutter | Targeting **Android** (decided) |
| Language | Dart | |
| State mgmt | Plain `setState` + `StreamBuilder` | No state-management package (kept simple for a 3-screen app) |
| Firebase | `firebase_core`, `firebase_auth`, `firebase_database`, `shared_preferences` | Email/password login, Realtime Database streams, local link/key storage |

## Communication & Cloud

| Layer | Choice | Notes |
| --- | --- | --- |
| Board-to-board  | ESP-NOW | 250 B max payload; protocol in [`api.md`](api.md) |
| Board-to-cloud  | HTTPS REST to Firebase RTDB | Gateway board only |
| Cloud database  | Firebase Realtime Database | JSON tree; path scheme in `api.md` |
| Weather data | WeatherAPI.com (free tier) | Gateway fetches it; the app delivers the API key via `config/weather_key` |
| Provisioning | WiFiManager captive portal (gateway)| Branded portal (AP `RadiantCooling-AP`, 192.168.4.1); enter SSID/password once; reset button (GPIO 33) to re-provision |

## Documentation

| Tool | Purpose |
| --- | --- |
| Markdown | All documentation |
| Mermaid | Diagrams (architecture, flows) |

## Tooling & DevOps

| Tool | Purpose |
| --- | --- |
| Git / GitHub | Version control & hosting |
| Arduino IDE  | Firmware build, upload, serial monitor|
| Flutter SDK  | Android app build & test |
| Firebase CLI | Project config, emulator (optional)  |
| CI (future)  | Optional GitHub Actions for firmware + app builds |

## Alternatives considered

- **FreeRTOS directly on ESP32** instead of Arduino — more control,
  more effort; revisit only if scheduling needs grow.
- **PlatformIO** instead of Arduino IDE — nicer CLI/CI story, but Arduino IDE
  was chosen for simplicity of development and flashing.
- **MQTT broker (Mosquitto)** instead of ESP-NOW — great for larger fleets,
  but requires a router/broker on site; ESP-NOW fits 3 boards with no extra
  infrastructure.
- **Cloud Firestore** instead of Realtime Database — richer app queries, but
  much harder for ESP32 to authenticate against; RTDB is the ESP32-friendly
  choice.

## References

Per-topic reference material lives in [`references/`](../references/) —
ESP-NOW, Firebase-ESP-Client, WiFiManager, sensors, SSR, WeatherAPI, ESP32
pinout, dew point, and toolchain guides.

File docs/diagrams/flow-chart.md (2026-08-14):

# Flow Charts

> Control logic flows for the ESP32 firmware — matches the implemented code
> in `src/esp/` (the pump decision lives in `ClimateControl.cpp`).

## 1. Main Control Loops

The three boards are split into two roles: the **gateway** (`RadiantCoolingMonitor`, the only board with Wi-Fi + Firebase) and the **ESP-NOW peers** (`WaterChillerController`, `DehumidifierController`).

### 1a. Gateway loop (`RadiantCoolingMonitor`)

```mermaid
flowchart TD
    A["Start"] --> B["Init sensors, ESP-NOW peers, Wi-Fi + Firebase"]
    B --> C["Read local 6x DS18B20 sensors"]
    C --> D["Drain ESP-NOW queue (peer telemetry)"]
    D --> E["Fetch weather (throttled: WEATHER_POLL_S)"]
    E --> F["Compute pump decision - weather + sensors + dew point"]
    F --> G{"Decision changed?"}
    G -->|Yes| H["Send set_pumps cmd to chiller over ESP-NOW"]
    G -->|No| I["Write telemetry + control values to Firebase"]
    H --> I
    I --> J["Stream: process radiant/config changes (realtime)"]
    J --> K{"Config changed?"}
    K -->|Yes| L["Apply locally or forward cmd/config to peer"]
    K -->|No| M["Reconnect Wi-Fi/Firebase if dropped"]
    L --> M
    M --> N["Publish heartbeat"]
    N --> C
```

### 1b. Peer loop (`WaterChillerController`, `DehumidifierController`)

```mermaid
flowchart TD
    A["Start"] --> B["Init hardware + ESP-NOW (register gateway)"]
    B --> C["Read sensors"]
    C --> D["Run control logic"]
    D --> E["Update outputs (SSR: pumps / dehumidifier)"]
    E --> F["Send telemetry/state to gateway over ESP-NOW"]
    F --> G{"ESP-NOW message received?"}
    G -->|cmd/config| H["Apply command / update configuration"]
    G -->|No| C
    H --> C
```

## 2. Water Pump Control Logic (computed on the gateway)

The pump decision is **not** made on the chiller board — the gateway
(`RadiantCoolingMonitor`) computes it from the WeatherAPI outdoor weather
(API key managed by the app) and all ESP sensor readings, then sends a
`set_pumps` command to the chiller. The chiller board only executes
commands (with a local fail-safe: pumps off if its water sensor is lost).

```mermaid
flowchart TD
    A["Inputs: outdoor dew point + temp (WeatherAPI), DHT22 temp + humidity, supply/return + pipe temps (DS18B20), chiller tank temp"]
    A --> B["Indoor dew point = Magnus(DHT22 temp, humidity)"]
    B --> C["Ref dew point = max(outdoor, indoor)"]
    C --> D["Water floor = ref dew point + margin"]
    D --> E{"Weather demand?<br/>(outdoor temp &gt; weather_cool_temp)"}
    E -->|Yes| F{"Sensor demand?<br/>(indoor DHT22 temp &gt; comfort setpoint)"}
    E -->|No| G["Pumps OFF"]
    F -->|Yes| H{"Coldest pipe/tank above floor?"}
    F -->|No| G
    H -->|Yes| I["Pumps ON"]
    H -->|No| G
    G --> J["Send set_pumps cmd to chiller (on change only)"]
    I --> J
```

> Draft thresholds (tunable via `config/control` in Firebase): comfort
> setpoint 24 °C, dew-point margin 2 °C, weather demand above 28 °C,
> hysteresis 1 °C. Hysteresis is applied by comparing against the floor
> ± margin depending on whether the pumps are already running.

## 3. Dehumidifier Control Logic

`DehumidifierController` — holds indoor relative humidity at the **55%**
setpoint (read from its own DHT22), with hysteresis. The humidity reading is
also sent to the gateway for the chiller dew-point computation.

```mermaid
flowchart TD
    A["Read DHT22 temperature + humidity"] --> B{"Humidity &gt; 55% + deadband?"}
    B -->|Yes| C["Dehumidifier ON (SSR)"]
    B -->|No| D{"Humidity &lt; 55% - deadband?"}
    D -->|Yes| E["Dehumidifier OFF"]
    D -->|No| F["Keep current state (hysteresis)"]
    C --> G["Send telemetry to gateway (temp, humidity, state)"]
    E --> G
    F --> G
```

> Setpoint 55 %RH, deadband 5 %RH by default (tunable via `config/dh`).

## Notes

- Hysteresis (deadbands) is applied to all switching logic to prevent SSR
  chatter and short-cycling of the pumps/dehumidifier.
- Fail-safe behaviour (e.g. pump override on sensor failure) is handled
  outside these flows and should be documented per-controller.

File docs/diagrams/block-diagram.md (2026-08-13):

# Block Diagram

> Hardware block diagram of the radiant cooling installation: ESP32 boards
> linked over ESP-NOW, with the gateway board carrying Wi-Fi + Firebase.
> All sensor readings are collected by the gateway and pushed to Firebase.

## Hardware summary

| Board | Sensors | Actuators (SSR) | Role |
| --- | --- | --- | --- |
| `RadiantCoolingMonitor` | 6x DS18B20 (1-Wire) | — | Gateway  |
| `WaterChillerController` | 1x DS18B20 | 2x SSR → 2 water pumps | Peer |
| `DehumidifierController` | 1x DHT22 (temp + humidity) | 1x SSR → dehumidifier | Peer |

## Diagram

```mermaid
flowchart LR
    subgraph PWR["Power (220V AC → 5V / 3A, one per board)"]
        PS1["PSU 1"]
        PS2["PSU 2"]
        PS3["PSU 3"]
    end

    subgraph CTRL["ESP32 Controllers (ESP-NOW)"]
        GW["RadiantCoolingMonitor<br/>(gateway)"]
        WCC["WaterChillerController"]
        DHC["DehumidifierController"]
    end

    subgraph SEN["Sensors"]
        T6["6x DS18B20<br/>(supply/return + pipes)"]
        T1["1x DS18B20<br/>(water temp)"]
        DHT["1x DHT22<br/>(temp + humidity)"]
    end

    subgraph BTN["Control"]
        RESET["WiFi Reset Button<br/>(hold 3 s)"]
    end

    subgraph ACT["Actuators (SSR)"]
        P1["Water Pump 1"]
        P2["Water Pump 2"]
        DHU["Dehumidifier"]
    end

    subgraph CLOUD["Cloud"]
        FB[("Firebase Realtime Database")]
        WX[("WeatherAPI.com")]
    end

    subgraph APP["Application"]
        UI["RadiantCooling App<br/>(Flutter - Android)"]
    end

    PS1 --> GW
    PS2 --> WCC
    PS3 --> DHC

    GW <-->|"ESP-NOW"| WCC
    GW <-->|"ESP-NOW"| DHC

    GW ---|"1-Wire"| T6
    GW ---|"GPIO 33"| RESET
    WCC ---|"1-Wire"| T1
    DHC ---|"DHT"| DHT

    WCC -->|"SSR"| P1
    WCC -->|"SSR"| P2
    DHC -->|"SSR"| DHU

    GW <-->|"Wi-Fi / HTTPS"| FB
    GW <-->|"HTTPS"| WX
    FB <-->|"Firebase SDK"| UI
```

## Data flow

1. Each board reads its own sensors.
2. Peers send `telemetry`/`state` to the gateway over ESP-NOW.
3. The gateway combines its 6x DS18B20 readings with peer data and writes
   everything to Firebase (`radiant/telemetry/...`).
4. The app reads from Firebase via the SDK.

## Blocks

| Block | Role | Description |
| --- | --- | --- |
| `RadiantCoolingMonitor`  | **Gateway** | Wi-Fi + Firebase + ESP-NOW; reads 6x DS18B20 |
| `WaterChillerController` | ESP-NOW peer | Reads 1x DS18B20; controls 2 water pumps via 2 SSRs  |
| `DehumidifierController` | ESP-NOW peer | Reads 1x DHT22; controls dehumidifier via 1 SSR |
| 6x DS18B20 | Sensor | Water supply/return + 4 pipe temps above the ceiling (monitor) |
| 1x DS18B20 | Sensor | Chiller loop water temperature |
| 1x DHT22 | Sensor | Temperature + humidity for dew-point control |
| WiFi reset button | Control | GPIO 33 → GND; hold 3 s to erase WiFi credentials |
| Water pumps (2) | Actuator | Circulate chilled water (SSR-controlled) |
| Dehumidifier | Actuator | Removes humidity (SSR-controlled) |
| Power supplies (3) | Power | One 220V→5V/3A supply per board (isolated) |
| Firebase RTDB | Cloud | Shared database for app and firmware |
| WeatherAPI.com | Cloud | Outdoor dew point + temperature; gateway calls it with the app-managed key |
| `RadiantCooling` app | App | Monitoring and configuration UI (Android) |

## Notes

- Only the gateway board uses Wi-Fi; peers are Wi-Fi-free (lower power,
  simpler setup).
- All boards must operate on the same Wi-Fi channel for ESP-NOW (see
  `docs/api.md`).

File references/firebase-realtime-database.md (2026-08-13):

# Firebase Realtime Database + FirebaseClient (Mobizt)

> The cloud store shared by the gateway and the Flutter app, and the async
> C++ client library used on the ESP32.

## Firebase Realtime Database

- NoSQL JSON tree, synced in real time over a single HTTPS connection.
- Every node is a URL path: `https://<project>.firebaseio.com/radiant/...`.
- **Streaming:** clients can listen to a path and receive events whenever any
  value under it changes (this replaces polling).
- **Security rules** decide who can read/write each path — see
  `docs/api.md §8`. Ready-to-use rules for the `radiant/` tree:
  `docs/firebase-security-rules.json` (gateway = email/password account,
  identified by `auth.token.email`; app = any authenticated user).

## FirebaseClient library (Mobizt)

- The **current** ESP32 client (the older `Firebase-ESP-Client` is
  **deprecated / end-of-life**). Install via Arduino Library Manager as
  **"FirebaseClient"**.
- **Async, non-blocking:** requests are queued and processed in the
  background; call the library loops every main-loop cycle.
- Auth in this project: **anonymous** (default) or **email/password** —
  whichever provider is enabled in the Firebase console.

### Core pattern

```cpp
DefaultNetwork   network;
FirebaseApp      app;
AsyncClientClass aClient(network);
RealtimeDatabase rtdb;

UserAuth auth(API_KEY);                          // anonymous
// UserAuth auth(API_KEY, "user@mail.com", "pass"); // email/password

initializeApp(aClient, app, getAuth(auth), aClient.loop);
app.getApp<RealtimeDatabase>(rtdb);
rtdb.url(DATABASE_URL);

rtdb.set<String>(aClient, "/path", "{...}");     // write JSON
rtdb.update<String>(aClient, "/path", "{...}");  // partial update
rtdb.stream(aClient, "/path", eventCb, timeoutCb); // realtime listener

void loop() {
  network.loop();
  app.loop();
  aClient.loop();
  // queue writes only when app.ready() && !aClient.isBusy()
}
```

Stream event callback: `aResult.isStream() && aResult.isData()`, payload via
`aResult.to<String>()`, changed node via `aResult.dataPath()`.

## How it is used here

- `FirebaseSync` module (gateway only): `setJson()` / `updateJson()` write
  `radiant/telemetry/*` and `radiant/state/*`; `stream()` listens to
  `radiant/config` in real time. The stream auto-starts in `loop()` once the
  async sign-in completes and re-arms on reconnect.
- The gateway must sign in with **email/password** (not anonymous) for the
  `firebase-security-rules.json` writer role to match (`auth.token.email`).
- `docs/api.md` defines the full data schema.

## Links

- Firebase RTDB docs: <https://firebase.google.com/docs/database>
- Mobizt FirebaseClient: <https://github.com/mobizt/FirebaseClient>
- Firebase-ESP-Client (deprecated): <https://github.com/mobizt/Firebase-ESP-Client>
- RNT — ESP32 + Firebase RTDB: <https://randomnerdtutorials.com/esp32-firebase-realtime-database/>

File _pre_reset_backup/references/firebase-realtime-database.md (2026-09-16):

# Firebase Realtime Database + Firebase-ESP-Client (Mobizt v4.4.17)

> The cloud store shared by the gateway and the Flutter app, and the async
> C++ client library used on the ESP32.

## Firebase Realtime Database

- NoSQL JSON tree, synced in real time over a single HTTPS connection.
- Every node is a URL path: `https://<project>.firebaseio.com/radiant/...`.
- **Streaming:** clients can listen to a path and receive events whenever any
  value under it changes (this replaces polling).
- **Security rules** decide who can read/write each path — see
  `docs/api.md §8`. Ready-to-use rules for the `radiant/` tree:
  `docs/firebase-security-rules.json` (gateway = email/password account,
  identified by `auth.token.email`; app = any authenticated user).

## Firebase-ESP-Client library (Mobizt v4.4.17)

- Install via Arduino Library Manager as **"Firebase Arduino Client Library
  for ESP8266 and ESP32"** by Mobizt, version **4.4.17**.
- **Async, non-blocking:** requests are queued and processed in the
  background; call `Firebase.loop()` every main-loop cycle.
- Auth in this project: **email/password** (required: security rules
  identify the gateway by `auth.token.email`).

### Core pattern

```cpp
FirebaseData fbdo;                 // regular requests
FirebaseData streamFbdo;           // stream connection
FirebaseAuth auth;
FirebaseConfig config;

config.database_url = DATABASE_URL;
config.api_key = API_KEY;
config.auth.token.email = EMAIL;
config.auth.token.password = PASSWORD;

Firebase.begin(&config, &auth);
Firebase.reconnectWiFi(true);

// Write
Firebase.setJSON(fbdo, "/path", jsonStr);        // overwrite
Firebase.updateNode(fbdo, "/path", jsonStr);     // partial update
Firebase.deleteNode(fbdo, "/path");              // delete

// Stream
streamFbdo.setStreamCallback(callback, timeoutCallback, 1000);
Firebase.beginStream(streamFbdo, "/path");

void loop() {
  Firebase.loop();
  Firebase.readStream(&streamFbdo);  // keep stream alive
}
```

Stream callback: `result.dataPath()` for the changed node,
`result.stringData()` for the JSON payload.

## How it is used here

- `FirebaseSync` module (gateway only): `setJson()` / `updateJson()` write
  `radiant/telemetry/*` and `radiant/state/*`; `stream()` listens to
  `radiant/config` in real time. The stream auto-starts in `loop()` once the
  async sign-in completes and re-arms on reconnect.
- The gateway must sign in with **email/password** (not anonymous) for the
  `firebase-security-rules.json` writer role to match (`auth.token.email`).
- `docs/api.md` defines the full data schema.

## Links

- Firebase RTDB docs: <https://firebase.google.com/docs/database>
- Mobizt Firebase-ESP-Client: <https://github.com/mobizt/Firebase-ESP-Client>
- RNT — ESP32 + Firebase RTDB: <https://randomnerdtutorials.com/esp32-firebase-realtime-database/>

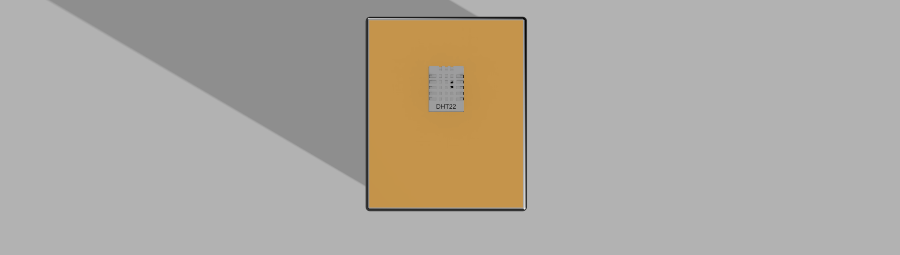
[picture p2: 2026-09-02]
models/dehumidifier_controller_front.png

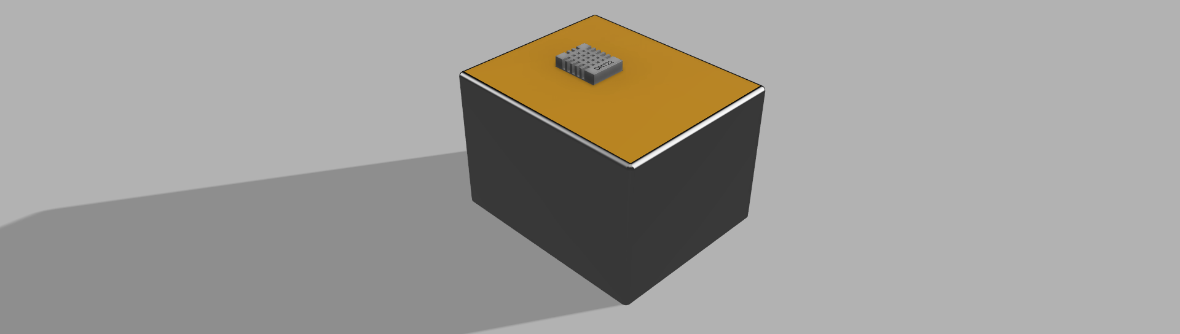
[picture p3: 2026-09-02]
models/dehumidifier_controller_left_slide.png

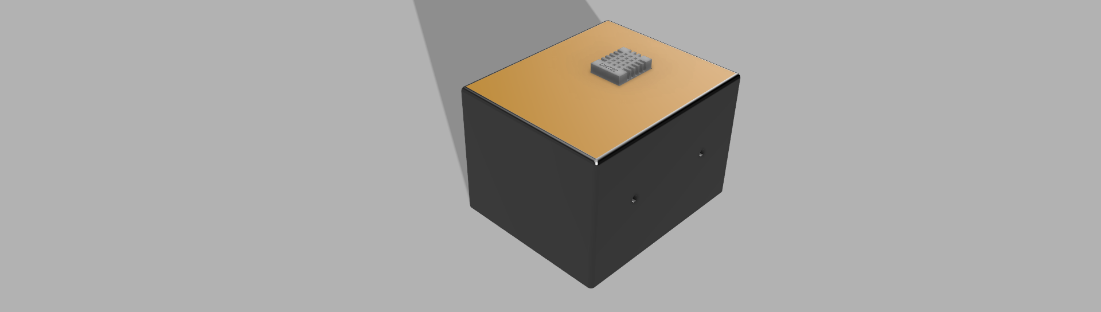
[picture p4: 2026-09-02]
models/dehumidifier_controller.png

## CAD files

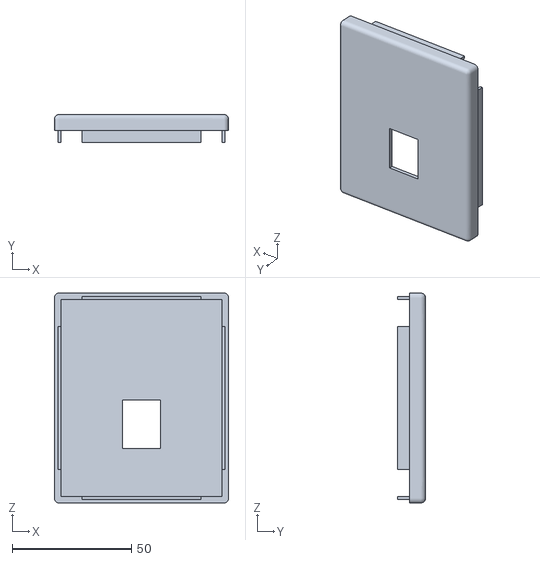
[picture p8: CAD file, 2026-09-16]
models/esp32_dht_22_ssr_outside_cover.stl
73.0 x 11.8 x 88.0

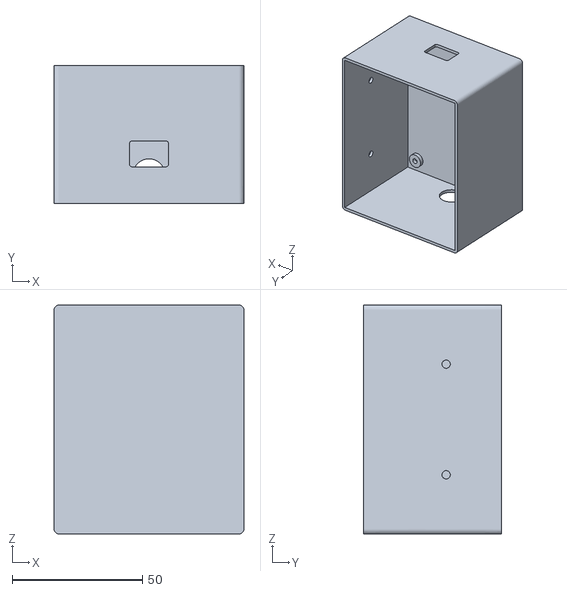
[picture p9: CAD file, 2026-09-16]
models/esp32_dht_22_ssr_case.stl
73.0 x 53.0 x 88.0

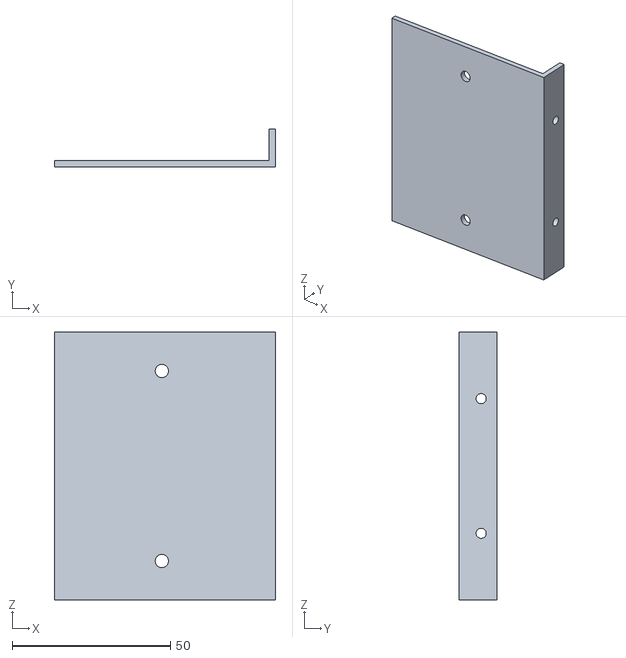
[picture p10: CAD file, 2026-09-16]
models/esp32_dht_22_ssr_inside_cover.stl
69.8 x 12.0 x 84.6

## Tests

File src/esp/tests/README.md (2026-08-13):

# Firmware Unit Tests

Host-machine tests for the pure-math modules of the ESP32 firmware.

## What is tested

| File | Module | Covers |
| --- | --- | --- |
| `test_climate_control.cpp` | `ClimateControl` (gateway) | Magnus dew point + pump decision logic (DHT22 demand, coldest-pipe/tank condensation floor, hysteresis, fail-safe, reference selection) |

The `ClimateControl` module has no Arduino hardware dependencies, so it is
compiled against the stub `Arduino.h` in this folder and run as a normal
desktop program (no Arduino toolchain required).

## Requirements

- `g++` (Linux, macOS, or Git Bash / WSL on Windows)

## Run

```bash
cd src/esp/tests
./run_tests.sh
```

Exit code `0` = all checks passed.

## Adding tests

- Add a test function in the relevant `test_*.cpp`, call it from `main()`,
  and use `CHECK(...)` / `CHECK_CLOSE(actual, expected, tol)`.
- Add more modules here the same way — the stub `Arduino.h` only needs to
  be extended if a module under test uses additional Arduino core APIs.

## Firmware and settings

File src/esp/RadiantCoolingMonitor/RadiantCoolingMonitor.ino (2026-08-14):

/*
 * RadiantCoolingMonitor.ino
 *
 * ESP32 GATEWAY - reads 6x DS18B20 temperature sensors, receives ESP-NOW
 * packets from the chiller and dehumidifier boards, fetches outdoor
 * weather from WeatherAPI.com (API key managed by the Flutter app), and
 * syncs all sensor data to Firebase Realtime Database. Also computes the
 * water chiller pump control (weather + sensors + condensation).
 *
 * Firebase is two-way (Mobizt FirebaseClient, async):
 *   - SAVE:    telemetry/state written to radiant/telemetry/* via setJson()
 *   - RECEIVE: radiant/config streamed in real time - app changes arrive
 *              immediately and are applied or forwarded over ESP-NOW
 *
 * WiFi is provisioned with the WiFiManager library (captive portal on first
 * boot; hold the reset button ~3 s to erase saved SSID/password).
 *
 * This file is glue only. All component/library code is encapsulated:
 *   Config.h            - board configuration (MACs, credentials, constants); includes PINS_CONFIG.h
 *   PINS_CONFIG.h       - pin assignments (1-Wire, WiFi reset button)
 *   TemperatureSensor   - wraps OneWire + DallasTemperature (6x DS18B20)
 *   WifiProvisioner     - wraps WiFiManager (captive-portal provisioning)
 *   EspNowTransport     - wraps WiFi + esp_now (register peers, send/receive)
 *   JsonProtocol        - wraps ArduinoJson (ESP-NOW message envelope)
 *   FirebaseSync        - wraps FirebaseClient (set/update + realtime stream)
 *   WeatherApi          - wraps HTTPClient (WeatherAPI.com; key from the app)
 *   ClimateControl      - dew point + pump decision (control computation)
 *
 * See docs/ for architecture, API and control logic.
 */

#include "Config.h"
#include "TemperatureSensor.h"
#include "WifiProvisioner.h"
#include "EspNowTransport.h"
#include "JsonProtocol.h"
#include "FirebaseSync.h"
#include "WeatherApi.h"
#include "ClimateControl.h"

#include <freertos/FreeRTOS.h>
#include <freertos/queue.h>
#include <time.h>

// ---- Components ----
TemperatureSensor loopTemps(PIN_ONE_WIRE, TEMP_COUNT);
WifiProvisioner wifi(WIFI_AP_NAME, PIN_WIFI_RESET_BUTTON);
EspNowTransport espNow;
FirebaseSync cloud;
WeatherApi weather(WEATHER_LOCATION);

// ---- Telemetry state ----
unsigned long lastPublishMs = 0;
unsigned long lastWeatherMs = 0;          // last weather fetch attempt (poll throttle)
unsigned long lastWeatherUpdateMs = 0;    // when a weather fetch last succeeded
uint32_t seq = 0;

// ---- Control state ----
bool weatherValid = false;        // true while a weather fetch succeeded recently
float outdoorHumidityPct = 0.0f;  // outdoor RH (display only - not used by the control logic)
ControlInputs inputs;             // latest values from all sources
ControlParams  params;            // defaults; updated from the config stream
bool pumpsOn = false;

// ESP-NOW receive -> Firebase write is decoupled via a FreeRTOS queue:
// the receive callback ONLY enqueues raw bytes (never blocks / decodes /
// calls Firebase inside the callback); loop() drains and processes.

typedef struct {
  uint8_t mac[6];
  uint8_t data[250];         // ESP-NOW max payload
  size_t  len;
} EspNowRxPacket;
QueueHandle_t espNowQueue;

// ---- Helpers ----

// Unix time once NTP syncs; uptime seconds as a fallback.
uint32_t nowUnix() {
  time_t t = time(nullptr);
  return t > 1000000000UL ? (uint32_t)t : (uint32_t)(millis() / 1000UL);
}

// Encode + send a JSON message to one peer.
void sendTo(const uint8_t* mac, MsgType type, const JsonDocument& payload) {
  char buf[250];
  size_t n = JsonProtocol::encode(type, DEVICE_ID, ++seq, payload, buf, sizeof(buf));
  // n == maxLen means the JSON was truncated (serializeJson caps at maxLen).
  if (n > 0 && n < sizeof(buf)) espNow.sendTo(mac, (const uint8_t*)buf, n);
}

// Gateway -> chiller: set_pumps command.
void sendPumpCmd(bool on) {
  JsonDocument payload;
  payload["cmd"]   = "set_pumps";
  payload["value"] = on ? "on" : "off";
  sendTo(PEER_CHILLER, MsgType::Cmd, payload);
  Serial.printf("[gateway] cmd chiller: set_pumps %s\n", on ? "on" : "off");
}

// ---- ESP-NOW receive callback: enqueue only, do not block ----
void handleMessage(const uint8_t* mac, const uint8_t* data, size_t len) {
  if (len == 0 || len > 250 || !espNowQueue) return;
  EspNowRxPacket pkt;
  memcpy(pkt.mac, mac, 6);
  memcpy(pkt.data, data, len);
  pkt.len = len;
  // esp_now callbacks run in the espnow TASK context, so xQueueSend is correct.
  if (xQueueSend(espNowQueue, &pkt, 0) != pdTRUE) {
    Serial.println("[espnow] RX queue full - packet dropped");
  }
}

// ---- Process one decoded message from a peer ----
void handleIncoming(IncomingMessage& msg) {
  Serial.printf("[espnow] rx type=%d src=%s seq=%u\n",
                (int)msg.type, msg.src.c_str(), msg.seq);

  if (msg.type == MsgType::Telemetry) {
    // Cache the latest peer readings for the chiller control computation.
    if (msg.src == "dh") {
      inputs.indoorTempC       = msg.data["temp_c"] | -100.0f;
      inputs.indoorHumidityPct = msg.data["humidity_pct"] | 0.0f;
    } else if (msg.src == "chiller") {
      inputs.waterTempC = msg.data["water_temp_c"] | -100.0f;
    }
    // Forward to Firebase: radiant/telemetry/<src>/latest (stamped ts)
    msg.data["ts"] = nowUnix();
    String path = String(RadiantFirebaseConfig::getTelemetryBasePath()) +
                  "/" + msg.src + "/latest";
    char json[512];
    serializeJson(msg.data, json, sizeof(json));
    cloud.setJson(path.c_str(), json);
  } else if (msg.type == MsgType::State) {
    // Forward to Firebase: radiant/state/<src>
    String path = String(RadiantFirebaseConfig::getStateBasePath()) + "/" + msg.src;
    char json[256];
    serializeJson(msg.data, json, sizeof(json));
    cloud.setJson(path.c_str(), json);
  } else if (msg.type == MsgType::Status && msg.src == "chiller") {
    // Peer booted after us - re-send the current pump state so it converges.
    sendPumpCmd(pumpsOn);
  }
  // Other messages (status from dh, unknown) are logged only.
}

// ---- Firebase realtime stream handler (radiant/config) ----
void onConfigStream(const char* path, const String& json) {
  Serial.printf("[config] %s -> %s\n", path, json.c_str());

  JsonDocument doc;
  if (deserializeJson(doc, json) != DeserializationError::Ok) return;

  // /radiant/config/control/params (+ children) -> update chiller control params
  if (String(path).startsWith(RadiantFirebaseConfig::getConfigControlParamsPath())) {
    if (doc["comfort_setpoint_c"].is<float>())
      params.comfortSetpointC = doc["comfort_setpoint_c"];
    if (doc["dewpoint_margin_c"].is<float>())
      params.dewPointMarginC = doc["dewpoint_margin_c"];
    if (doc["weather_cool_temp_c"].is<float>())
      params.weatherCoolTempC = doc["weather_cool_temp_c"];
    Serial.printf("[config] control params: setpoint=%.1f margin=%.1f weather=%.1f\n",
                  params.comfortSetpointC, params.dewPointMarginC,
                  params.weatherCoolTempC);
  }
  // /radiant/config/weather_key (written by the Flutter app) -> API key
  else if (String(path).startsWith(RadiantFirebaseConfig::getConfigWeatherKeyPath())) {
    const char* key = doc.as<const char*>();
    if (key != nullptr && key[0] != '\0') {
      weather.setKey(key);
      Serial.println("[config] weather key updated");
    }
  }
  // /radiant/config/dh (+ children) -> forward dehumidifier config over ESP-NOW
  else if (String(path).startsWith(RadiantFirebaseConfig::getConfigDhPath())) {
    JsonDocument payload;
    payload["humidity_setpoint_pct"] = doc["humidity_setpoint_pct"] | 55.0f;
    payload["humidity_deadband_pct"] = doc["humidity_deadband_pct"] | 5.0f;
    sendTo(PEER_DEHUM, MsgType::Config, payload);
  }
}

void setup() {
  Serial.begin(115200);

  espNowQueue = xQueueCreate(8, sizeof(EspNowRxPacket));

  loopTemps.begin();

  // Connect Wi-Fi FIRST (so ESP-NOW + Firebase share the router channel).
  // WiFiManager opens a "RadiantCooling-AP" portal when there are no saved
  // credentials or the network is unreachable.
  if (!wifi.begin()) {
    Serial.println("WiFi not connected - connect to AP 'RadiantCooling-AP' to configure");
    ESP.restart();
  }
  configTime(0, 0, "pool.ntp.org", "time.nist.gov");   // for telemetry ts

  if (!espNow.begin()) {
    Serial.println("ESP-NOW init failed");
    return;
  }
  // IMPORTANT (WiFiManager + ESP-NOW): the gateway is now on the ROUTER's
  // Wi-Fi channel (whatever channel the router uses). The ESP-NOW peers sit
  // on channel 1 by default, so fix the router to 1/6/11 and/or configure
  // the peers' channel to match - otherwise they won't hear the gateway.
  // The gateway's channel is published in the heartbeat for reference.
  espNow.addPeer(PEER_CHILLER);
  espNow.addPeer(PEER_DEHUM);
  espNow.onReceive(handleMessage);   // enqueue only - decoded in loop()

  // Firebase (async): auth + realtime stream on the config path.
  // The stream auto-starts in cloud.loop() once sign-in completes.
  // Credentials/URLs come from FirebaseConfig (values in the git-ignored
  // FirebaseConfig.cpp).
  FirebaseSync::Config fbCfg = {
    RadiantFirebaseConfig::getDatabaseURL(),
    RadiantFirebaseConfig::getApiKey(),
    RadiantFirebaseConfig::getAuthEmail(),
    RadiantFirebaseConfig::getAuthPassword(),
  };
  cloud.begin(fbCfg);
  cloud.stream(RadiantFirebaseConfig::getConfigPath(), onConfigStream);
}

void loop() {
  // WiFi reset button: hold ~3 s to erase credentials and restart.
  // Also auto-reconnects (rate-limited) after a drop.
  wifi.handleResetButton(WIFI_RESET_HOLD_MS);
  wifi.reconnectIfLost();

  // Firebase async processing (network, auth token, stream heartbeats)
  cloud.loop();

  // Read local 6x DS18B20 sensors
  loopTemps.requestTemperatures();
  delay(750);                                  // DS18B20 conversion time

  // Sensor inputs: chilled-water supply/return + pipe temperatures from the
  // local DS18B20 array (index roles in Config.h). Coldest pipe = min of the
  // VALID readings - the true anti-condensation surface above the ceiling.
  float pipeTemps[TEMP_COUNT];
  for (uint8_t i = 0; i < loopTemps.count(); i++) pipeTemps[i] = loopTemps.readC(i);
  inputs.supplyTempC  = pipeTemps[IDX_SUPPLY];
  inputs.returnTempC  = pipeTemps[IDX_RETURN];
  inputs.coldestPipeC = ClimateControl::coldestValidC(pipeTemps, loopTemps.count());

  // Drain the ESP-NOW RX queue: peer telemetry/state/status
  EspNowRxPacket pkt;
  while (espNowQueue && xQueueReceive(espNowQueue, &pkt, 0) == pdTRUE) {
    IncomingMessage msg;
    if (JsonProtocol::decode((const char*)pkt.data, pkt.len, msg)) {
      handleIncoming(msg);
    }
  }

  // Weather refresh (throttled - see WEATHER_POLL_S). The API key comes
  // from the Flutter app via the config/weather_key stream (runtime, not
  // compiled in); without it no fetch is attempted.
  if (weather.hasKey() && millis() - lastWeatherMs >= WEATHER_POLL_S * 1000UL) {
    lastWeatherMs = millis();
    WeatherConditions wx = weather.fetch();
    if (wx.ok) {
      inputs.outdoorTempC      = wx.tempC;
      inputs.outdoorDewPointC  = wx.dewPointC;
      outdoorHumidityPct       = wx.humidityPct;
      weatherValid = true;
      lastWeatherUpdateMs = millis();
      Serial.printf("[weather] ok: temp=%.1f dewpoint=%.1f\n",
                    inputs.outdoorTempC, inputs.outdoorDewPointC);
    } else {
      Serial.println("[weather] fetch failed (key missing or invalid)");
    }
  }

  // Drop weather when it goes stale (API unreachable, bad key, or the app
  // never sent one): weather demand turns off and the condensation floor
  // falls back to the indoor dew point.
  if (weatherValid && millis() - lastWeatherUpdateMs >= WEATHER_STALE_S * 1000UL) {
    weatherValid = false;
    inputs.outdoorTempC      = -100.0f;
    inputs.outdoorDewPointC  = -100.0f;
    outdoorHumidityPct       = -100.0f;
    Serial.println("[weather] stale - indoor dew point only");
  }

  // Control computation (weather + sensors + condensation, see flow-chart.md)
  ControlDecision d = ClimateControl::decidePumps(inputs, params, pumpsOn);
  if (d.pumpsOn != pumpsOn) {
    pumpsOn = d.pumpsOn;
    sendPumpCmd(pumpsOn);
  }

  // ---- SAVE: telemetry + heartbeat to Firebase (non-blocking) ----
  if (millis() - lastPublishMs >= TELEMETRY_S * 1000UL) {
    lastPublishMs = millis();

    // radiant/telemetry/monitor/latest (temps_c = [supply, return, pipe1..4])
    JsonDocument tel;
    JsonArray temps = tel["temps_c"].to<JsonArray>();
    for (uint8_t i = 0; i < loopTemps.count(); i++) temps.add(loopTemps.readC(i));
    tel["supply_c"]       = inputs.supplyTempC;
    tel["return_c"]       = inputs.returnTempC;
    tel["coldest_pipe_c"] = inputs.coldestPipeC;
    tel["delta_t_c"] = (inputs.returnTempC > kTempValidLoC && inputs.returnTempC < kTempValidHiC &&
                        inputs.supplyTempC > kTempValidLoC && inputs.supplyTempC < kTempValidHiC)
                            ? inputs.returnTempC - inputs.supplyTempC : 0.0f;
    tel["outdoor_temp_c"]      = inputs.outdoorTempC;
    tel["outdoor_dewpoint_c"]  = inputs.outdoorDewPointC;
    tel["outdoor_humidity_pct"] = outdoorHumidityPct;
    tel["dew_point_c"]    = d.refDewPointC;
    tel["water_floor_c"]  = d.waterFloorC;
    tel["pumps"]          = pumpsOn ? "on" : "off";
    tel["ts"]             = nowUnix();
    char json[512];
    serializeJson(tel, json, sizeof(json));
    cloud.setJson(
      String(RadiantFirebaseConfig::getTelemetryBasePath()) + "/monitor/latest",
      json);

    // Retained heartbeat (exposes SYSTEM_ID for app linking + Wi-Fi channel)
    JsonDocument hb;
    hb["online"]    = true;
    hb["firmware"]  = "0.1.0";
    hb["channel"]   = WiFi.channel();
    hb["device_id"] = SYSTEM_ID;
    hb["ts"]        = nowUnix();
    char hbJson[256];
    serializeJson(hb, hbJson, sizeof(hbJson));
    cloud.setJson(RadiantFirebaseConfig::getHeartbeatPath(), hbJson);

    // Device registry - the app discovers/links this system via SYSTEM_ID.
    JsonDocument dev;
    dev["online"]    = true;
    dev["firmware"]  = "0.1.0";
    dev["channel"]   = WiFi.channel();
    dev["device_id"] = SYSTEM_ID;
    dev["ts"]        = nowUnix();
    char devJson[256];
    serializeJson(dev, devJson, sizeof(devJson));
    cloud.setJson(
      String(RadiantFirebaseConfig::getDevicesBasePath()) + "/" + SYSTEM_ID,
      devJson);
  }

  delay(100);
}

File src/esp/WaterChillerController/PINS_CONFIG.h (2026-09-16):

#pragma once
#include <Arduino.h>

static const uint8_t PIN_SSR_COMPRESSOR = 18;
static const uint8_t PIN_RELAY_PUMP1    = 21;
static const uint8_t PIN_RELAY_PUMP2    = 22;

static const uint8_t PIN_TEMP_OUTGOING = 32;
static const uint8_t PIN_TEMP_INGOING  = 23;
static const uint8_t PIN_TEMP_TANK     = 19;

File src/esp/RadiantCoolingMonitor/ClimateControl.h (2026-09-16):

#pragma once
#include <Arduino.h>

static const float kTempValidLoC = -90.0f;
static const float kTempValidHiC =  60.0f;

struct ControlInputs {
  float outdoorTempC     = 0.0f;
  float outdoorDewPointC = 0.0f;
  float indoorTempC      = 0.0f;
  float indoorHumidityPct = 0.0f;
  float supplyTempC      = 0.0f;
  float returnTempC      = 0.0f;
  float coldestPipeC     = -100.0f;
  float waterTempC       = 0.0f;
};

struct ControlParams {
  float comfortSetpointC = 24.0f;
  float dewPointMarginC  = 2.0f;
  float weatherCoolTempC = 28.0f;
  float hysteresisC      = 1.0f;
};

struct ControlDecision {
  bool  pumpsOn;
  float refDewPointC;
  float waterFloorC;
  bool  weatherDemand;
  bool  sensorDemand;
};

class ClimateControl {
public:
  static float dewPointC(float tempC, float humidityPct);

  static float coldestValidC(const float* temps, uint8_t n);

  static ControlDecision decidePumps(const ControlInputs& in,
                                     const ControlParams& p,
                                     bool currentlyOn);
};

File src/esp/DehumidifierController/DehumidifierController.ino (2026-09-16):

#include "Config.h"
#include "HumiditySensor.h"
#include "SsrOutput.h"
#include "EspNowTransport.h"
#include "JsonProtocol.h"

#include <freertos/FreeRTOS.h>
#include <freertos/queue.h>

HumiditySensor roomClimate(PIN_DHT22);
SsrOutput dehumidifier(PIN_SSR_DEHUM);
EspNowTransport espNow;

float HUMIDITY_SETPOINT_PCT = 55.0;
float HUMIDITY_DEADBAND_PCT = 5.0;
bool  systemEnabled         = true;

unsigned long lastSendMs = 0;
uint32_t seq = 0;
float lastTempC       = -127.0f;
float lastHumidityPct = 0.0f;
uint8_t readFailures  = 0;
bool  failSafeTripped = false;

typedef struct {
  uint8_t mac[6];
  uint8_t data[250];
  size_t  len;
} EspNowRxPacket;
QueueHandle_t espNowQueue;


void sendMsg(MsgType type, const JsonDocument& payload) {
  char buf[250];
  size_t n = JsonProtocol::encode(type, DEVICE_ID, ++seq, payload, buf, sizeof(buf));
  if (n > 0 && n < sizeof(buf)) espNow.sendTo(GATEWAY_MAC, (const uint8_t*)buf, n);
}

void sendStatus() {
  JsonDocument payload;
  payload["online"]   = true;
  payload["firmware"] = "0.1.0";
  sendMsg(MsgType::Status, payload);
}

void handleMessage(const uint8_t* mac, const uint8_t* data, size_t len) {
  if (len == 0 || len > 250 || !espNowQueue) return;
  EspNowRxPacket pkt;
  memcpy(pkt.mac, mac, 6);
  memcpy(pkt.data, data, len);
  pkt.len = len;
  if (xQueueSend(espNowQueue, &pkt, 0) != pdTRUE) {
    Serial.println("[espnow] RX queue full - packet dropped");
  }
}

void handleSendResult(const uint8_t* mac, bool success) {
  Serial.printf("[espnow] send %s -> %02X:%02X:%02X:%02X:%02X:%02X\n",
                success ? "OK" : "FAIL",
                mac[0], mac[1], mac[2], mac[3], mac[4], mac[5]);
}

void handleConfig(const IncomingMessage& msg) {
  if (msg.data["humidity_setpoint_pct"].is<float>()) {
    HUMIDITY_SETPOINT_PCT = msg.data["humidity_setpoint_pct"];
    Serial.printf("[dh] setpoint -> %.1f %%RH\n", HUMIDITY_SETPOINT_PCT);
  }
  if (msg.data["humidity_deadband_pct"].is<float>()) {
    HUMIDITY_DEADBAND_PCT = msg.data["humidity_deadband_pct"];
    Serial.printf("[dh] deadband -> %.1f %%RH\n", HUMIDITY_DEADBAND_PCT);
  }
}

void handleCmd(const IncomingMessage& msg) {
  const char* cmd = msg.data["cmd"] | "";
  if (strcmp(cmd, "set_humidity_target") == 0) {
    HUMIDITY_SETPOINT_PCT = msg.data["value"] | HUMIDITY_SETPOINT_PCT;
    Serial.printf("[dh] set_humidity_target -> %.1f %%RH\n", HUMIDITY_SETPOINT_PCT);
  } else if (strcmp(cmd, "enable") == 0) {
    systemEnabled = true;
    Serial.println("[dh] enabled");
  } else if (strcmp(cmd, "disable") == 0) {
    systemEnabled = false;
    dehumidifier.off();
    Serial.println("[dh] disabled");
  } else if (strcmp(cmd, "reset") == 0) {
    Serial.println("[dh] reset");
    ESP.restart();
  }
  else {
    Serial.printf("[dh] unknown cmd: %s\n", cmd);
  }
}

void setup() {
  Serial.begin(115200);

  espNowQueue = xQueueCreate(8, sizeof(EspNowRxPacket));

  roomClimate.begin();
  dehumidifier.begin();

  if (!espNow.begin()) {
    Serial.println("ESP-NOW init failed");
    return;
  }
  espNow.addPeer(GATEWAY_MAC);
  espNow.onReceive(handleMessage);
  espNow.onSend(handleSendResult);

  sendStatus();
}

void loop() {
  float tempC, humidityPct;

  if (roomClimate.read(tempC, humidityPct)) {
    readFailures  = 0;
    failSafeTripped = false;
    lastTempC       = tempC;
    lastHumidityPct = humidityPct;
    if (systemEnabled) {
      if (humidityPct > HUMIDITY_SETPOINT_PCT + HUMIDITY_DEADBAND_PCT) {
        dehumidifier.on();
      } else if (humidityPct < HUMIDITY_SETPOINT_PCT - HUMIDITY_DEADBAND_PCT) {
        dehumidifier.off();
      }
    }
  } else {
    if (++readFailures >= 3 && !failSafeTripped) {
      failSafeTripped = true;
      dehumidifier.off();
      JsonDocument payload;
      payload["dehumidifier"] = "off";
      sendMsg(MsgType::State, payload);
      Serial.println("[dh] sensor read failed x3 - dehumidifier off (fail-safe)");
    }
  }

  EspNowRxPacket pkt;
  while (espNowQueue && xQueueReceive(espNowQueue, &pkt, 0) == pdTRUE) {
    IncomingMessage msg;
    if (JsonProtocol::decode((const char*)pkt.data, pkt.len, msg)) {
      if (msg.type == MsgType::Config) handleConfig(msg);
      else if (msg.type == MsgType::Cmd) handleCmd(msg);
    }
  }

  if (millis() - lastSendMs >= TELEMETRY_S * 1000UL) {
    lastSendMs = millis();
    JsonDocument payload;
    payload["temp_c"]        = lastTempC;
    payload["humidity_pct"]  = lastHumidityPct;
    payload["dehumidifier"]  = dehumidifier.isOn() ? "on" : "off";
    sendMsg(MsgType::Telemetry, payload);
  }

  delay(100);
}

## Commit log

2026-08-07 Initial commit: radiant cooling system - modular ESP32 firmware (ESP-NOW + Firebase) with Flutter app scaffold and docs
2026-08-07 Add WiFiManager provisioning, Firebase streaming, references
    - Gateway: WiFiManager captive portal + WiFi reset button (GPIO 33)
    - Gateway: FirebaseSync with realtime config streaming (set/update/stream, auto-rearm)
    - README: standard GitHub format with badges + author info
    - References: 12 per-topic reference files
    - Docs: consistency pass (safe pins, streaming flows, links)
2026-08-07 Isolate weather credentials; document per-board power supplies
    - Weather API key/location moved to git-ignored WEATHER_CONFIG.h (template: WEATHER_CONFIG.example.h)
    - Power: one 220V->5V/3A supply per board (references/power-supply.md, block diagram, pin-map, README)
    - Docs: api.md, esp README, weatherapi reference updated for the credential file
2026-08-07 Implement ESP-NOW handlers + telemetry across all three boards
    - Gateway: RX queue decoupling, peer telemetry/state forwarding to Firebase, pump cmd on decision change + boot re-sync, config stream handler (control params + dh forward), telemetry + retained heartbeat
    - Chiller: RX queue, set_pumps handler, state on pump change, telemetry, delivery status, boot status
    - Dehumidifier: RX queue, config/cmd handlers, 55%RH hysteresis + enable/disable, fail-safe after 3 sensor failures
    - Docs: implemented-behavior notes, ts stamping, roadmap checkboxes
    [DehumidifierController.ino, RadiantCoolingMonitor.ino, WaterChillerController.ino]
2026-08-13 Move WeatherAPI key to the Flutter app, add SYSTEM_ID device linking, rework ClimateControl for pipe-sensor layout
    [ClimateControl.h, RadiantCoolingMonitor.ino, WaterChillerController.ino]
2026-08-13 Invert weather design: ESP32 fetches weather, app only manages the API key
    [RadiantCoolingMonitor.ino]
2026-08-14 Finish the app (auth/dashboard/settings/linking) with widget tests, fix and deploy Firebase rules, and refactor gateway Firebase/WiFi config
    🤖 Generated with Codebuff
    [FirebaseSync.cpp, RadiantCoolingMonitor.ino, WifiProvisioner.cpp]
2026-08-14 Update docs to match current codebase and add wiring diagram
    - Mark api.md implemented, fix weather URL, ESP-NOW section numbering and QoS claim
    - Fill in tech-stacks.md state management and Firebase packages, fix table row
    - Refresh flow-chart, cirkit-designer and pin-map status; link wiring-diagram.png
    - Add schematic wiring diagram (PNG + editable SVG) matching the pin configs
    Generated with Codebuff 🤖
2026-09-02 feat: complete Flutter app with 10 screens, 3 services, and full test suite
    Expand the companion app from 4 screens to a full 10-screen application
    with 4-tab navigation, real-time data logging, alert detection, and
    onboarding tour.
    Screens added:
    - LoginScreen / RegisterScreen (split from combined AuthScreen)
    - OnboardingScreen (4-page swipeable tour, shown once on first launch)
    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
    [esp32_dht_22_srr_case.stl]
2026-10-15 feat(app): fix stream subscription error, add control UI, remove dead code
    - Fix 'Stream has already been listened to' in RadiantFirebase by
    returning fresh streams per call instead of cached late-final instances
    - Add pump on/off and auto/manual mode controls to DashboardScreen
    - Add mode field to MonitorTelemetry model
    - Wire RadiantFirebase.setLinkedId so control writes hit right path
    - Clean up unused _updateControlStream, unused imports, dead fields
    - Flutter analyze: 0 issues
2026-10-15 fix: ESP-NOW MAC addressing, broadcast Firebase streams, hide debug ribbon, fix app errors
    Firmware fixes:
    - Fix DehumidifierController GATEWAY_MAC: was own MAC, now monitor MAC (1C:69:20:A3:04:78)
    - Fix WaterChillerController GATEWAY_MAC: was own MAC, now monitor MAC
    - Remove unused PEER_MONITOR from Config.h
    - Add CustomFirebaseFS.h to reduce flash usage for huge_app partition
    - Update docs, pin maps, and README for accuracy
    App fixes:
    - Fix 'Stream has already been listened to' error by using .asBroadcastStream()
    - Fix flutter analyze errors (Icons.power_on, unused imports, etc.)
    - Hide debug ribbon (debugShowCheckedModeBanner: false)
    - Add pump control UI to Dashboard (pumps ON/OFF + au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
2026-10-15 fix(app): update sensor layout to match actual firmware
    - WaterChillerController: 2x DS18B20 (outgoing/inlet) + compressor + pump1
    - RadiantCoolingMonitor: 4x DS18B20 (ceiling pipes)
    - DehumidifierController: 1x DHT22
    - Update ChillerTelemetry model (outgoingTempC, ingoingTempC, compressorOn)
    - Update Dashboard screen (Tank temps section, Control section)
    - Update About screen hardware descriptions
    - Fix tests to match new ChillerState fields
2026-10-16 feat: finalize sensor/SSR pin assignments (GPIO5 for ceiling4), build release APK, update docs with pin-map and installer info, secure credentials in .gitignore
2026-10-16 chore: gitignore STL/GCODE 3D-print files, add new monitor case render images
